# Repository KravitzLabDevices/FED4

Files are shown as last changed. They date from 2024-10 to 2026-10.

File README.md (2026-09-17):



<p align="center">
  FED4 Demo
</p>

**FED4** (Feeding Experimentation Device) is an open-source Arduino library for mouse operant training on board **v1.7**. Hardware details and chipsets: [`CHIPSETS.md`](CHIPSETS.md).

## Hardware features (v1.7)

- **MCU** — ESP32-S3  
- **Feeding** — stepper pellet dispenser with photogate well sensing and jam-clear paths  
- **Nose pokes** — three ESP32-S3 capacitive touch pads (left / center / right) with light-sleep wake  
- **Photogates** — four IR gates (left / center / right poke lanes + pellet / drop path)  
- **Display** — Kyocera TN0216 320×176 MIP reflective mono panel (SPI + VCOM)  
- **Storage** — microSD (SPI) for session CSV logging  
- **Clock** — DS3231 RTC  
- **Environment** — BME680 (temp / humidity / pressure / gas), VEML7700 ambient light  
- **Battery** — LiPo monitoring via MAX17048 fuel gauge  
- **Motion / proximity** — PIR (EKMB1107112); VL53L1X time-of-flight; LIS3DH accelerometer on board  
- **User I/O** — three front buttons; MCP23017 GPIO expander (rails, haptics, solenoids, display control)  
- **Feedback** — WS2812 front RGB strip, red status LED, haptic motor, MAX98357A I2S speaker amp  
- **Expansion** — TRRS / GPIO header (audio or digital); dual solenoid drivers; user expander pins; optional servo/INT  
- **Power** — switched peripheral rails (PSV2 / PSV3 via TPS22917) for sleep current control  
- **Optional wireless** — [Hublink](docs/wiki/Wireless-and-Hublink.md) BLE sync  

Library sketches stay small via an event-driven idle path: `waitUntil()` → act → `update()`.

In-lab test firmware flashes (version on the display, CSV `LibraryVer`) are tracked in [`docs/firmware/`](docs/firmware/).

## Examples

| Sketch | Role |
| --- | --- |
| [`BasicFED4`](examples/1_Programs/BasicFED4/) | Left poke → feed (starter program) |
| [`FreeFeeding`](examples/1_Programs/FreeFeeding/) | Replace pellet when taken |
| [`2_UnitTests/`](examples/2_UnitTests/) | Hardware bring-up / domain checks  |

More programs will return under [`examples/1_Programs/`](examples/1_Programs/) as domains are verified. Deeper API notes live in [`docs/wiki/`](docs/wiki/) and the [GitHub Wiki](https://github.com/KravitzLabDevices/FED4/wiki).

## In Development

Open work tracked in detail in [`examples/2_UnitTests/SRC_AUDIT.md`](examples/2_UnitTests/SRC_AUDIT.md):

- [ ] Rebuild menu + silence UX for v1.7 display  
- [ ] Retest / clean button holds (silence, menu, Mario / jingles)  
- [ ] Port remaining behavioral programs from archive → [`1_Programs`](examples/1_Programs/)  
- [ ] PIR / motion idle path (deferred to v1.8 counter IC)  
- [ ] Revisit ActivityMonitor when that sketch is unarchived  
- [ ] **Sense / camera** — TRRS TRIG + UART path in [`examples/3_Submodules/`](examples/3_Submodules/) (`FED4::senseSyncTime` / `senseTrigPulse`). Validate chamber lighting + fixed AE under strip white.  
- [ ] Characterize touch / SD card write duration to determine max touch rate

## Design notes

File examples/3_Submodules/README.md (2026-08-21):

# FED4 Submodule TRRS UART Specification

**Version:** v1.0 (TRIG + UART)

This directory holds **standalone firmware** for satellite boards that communicate with FED4 over a 4-wire TRRS-style link (power + TRIG + DATA). Submodule code is **not** part of the FED4 core library and does not use `FED4.h` or any `src/` APIs except the mirrored wire format documented here.

**FED4 master (library):** `src/FED4_Submodule.cpp` — `FED4::senseBegin()` / `senseSyncTime()` / `senseTrigPulse()`.

## Pin map

| Signal | FED4 | Sense (XIAO ESP32-S3) |
|---|---|---|
| 3V3 / GND | connector power | connector power |
| TRIG | `AUDIO_TRRS_2` = GPIO5 | GPIO1 (D0) |
| DATA | `AUDIO_TRRS_3` = GPIO6 | GPIO2 (D1) |
| spare | `AUDIO_TRRS_1` = GPIO4 | — |

- Idle **TRIG = HIGH** (Sense `INPUT_PULLUP`); FED4 drives **LOW** to wake / fire.
- **DATA:** half-duplex UART 115200 8N1, same GPIO for RX+TX; **external pull-up to 3.3 V** required.

## Shared slave helpers

| File | Role |
|---|---|
| [`SubmoduleProtocol.h`](SubmoduleProtocol.h) | Text frames, error codes |
| [`SubmoduleState.h/.cpp`](SubmoduleState.h) | `rtcValid`, last filename |
| [`SubmoduleRtc.h/.cpp`](SubmoduleRtc.h) | `settimeofday` / live clock |
| [`SubmoduleCommands.h/.cpp`](SubmoduleCommands.h) | `T` / `R` UART dispatch |
| [`SubmoduleUartEsp32.h/.cpp`](SubmoduleUartEsp32.h) | TRIG light-sleep wake, capture-blocks-sleep, UART poll |

Board folders (e.g. [`SeeedStudioSense/`](SeeedStudioSense/)) provide pin maps, camera backend, and a thin `.ino` plus `SubmodulePort.cpp` that `#include`s the shared `.cpp` files.

## Relationship to FED4

| | FED4 (master) | Submodules (slaves) |
|---|---|---|
| Role | TRIG + UART master | TRIG wake + capture |
| Code | `src/FED4_Submodule.cpp` + `FED4::sense*` | `examples/3_Submodules/` only |

## Protocol

### Init (synchronous)

1. FED4 TRIG LOW  
2. Sense wakes, UART up, sends `RDY\n`  
3. FED4 sends `T <yyyy> <mm> <dd> <HH> <MM> <SS>\n`  
4. Sense sets RTC, replies `OK\n` (or `ERR <code>\n`)  
5. FED4 TRIG HIGH → Sense light sleep  

Until `rtcValid`, Sense **does not capture** on TRIG (UART/`T` only).

### Capture (asynchronous — fire and forget)

1. FED4: TRIG LOW for **~10 ms**, then HIGH (`senseTrigPulse`). No UART wait for capture.  
2. Sense: on TRIG active + `rtcValid`, **one** capture to `YYYYMMDDHHMMSS.jpg` (blocking). **Do not light-sleep while capturing**, even if TRIG returns HIGH.  
3. After capture: if TRIG still LOW, accept UART (`T`, `R <name>`); if HIGH, light sleep.  
4. Next HIGH→LOW after a completed cycle starts a new capture.

### UART frames (init / post-capture session)

| Line | Direction | Meaning |
|---|---|---|
| `RDY` | Sense→FED4 | UART ready |
| `T yyyy mm dd HH MM SS` | FED4→Sense | SET_TIME |
| `R <filename>` | FED4→Sense | Rename last capture |
| `OK` | Sense→FED4 | Success |
| `ERR <code>` | Sense→FED4 | Failure |

Capture itself has **no** OK/ERR handshake on the wire.

## Submodule index

| Folder | Board | Status |
|---|---|---|
| [SeeedStudioSense](SeeedStudioSense/) | Seeed XIAO ESP32-S3 Sense | v1.0 — TRIG capture, SET_TIME, optional rename |

**FED4 master test:** [`FED4-Submodule-SeeedStudioSense`](../2_UnitTests/FED4-Submodule-SeeedStudioSense/) — `senseSyncTime` + `senseTrigPulse`.

## Changelog

### v1.0
- Replaced I2C @ 0x42 with TRRS TRIG + half-duplex UART.
- Async TRIG pulse capture; sync SET_TIME at init.

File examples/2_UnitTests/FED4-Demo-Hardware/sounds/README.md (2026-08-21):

# Boot startup sound (embedded PCM)

`startup_sound.h` holds 48 kHz mono 16-bit PCM played once at boot.

## Regenerate from a new clip

```bash
python3 sounds/gen_startup_sound.py /path/to/your-audio.mp3
```

Requires macOS `afconvert` for MP3 input, or pass a WAV already at 48 kHz mono 16-bit LE.

## Flash cost

~96 KB per second of audio (~2.5 s ≈ 232 KB for the current clip).

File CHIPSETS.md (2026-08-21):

# Specific chipsets used in FED4

| Subsystem | Chip / module | Notes |
| --- | --- | --- |
| Main platform | **ESP32 (ESP32‑S3 family)** | Main MCU (library `architectures=esp32`; code notes ESP32‑S3 specifics) |
| Power / battery | **MAX17048** | LiPo fuel gauge / battery monitor |
| Timekeeping | **DS3231** | Real-time clock (RTC) |
| I/O expansion | **MCP23X17** (MCP23017 family) | GPIO expander (photogates, haptics control, ToF XSHUT, etc.) |
| Environmental sensing | **BME680** | Temperature / humidity / pressure / gas |
| Environmental sensing | **VEML7700** | Ambient light |
| Motion / presence | **EKMB1107112** | PIR motion sensor (digital GPIO, replaces STHS34PF80) |
| Distance / proximity  | **VL53L1X** | Time-of-flight (ToF) distance / proximity |
| Inertial (optional) | **LIS3DH** | 3-axis accelerometer (hardware present; optional in sketches) |
| Audio | **MAX98357A** | I2S audio amplifier (speaker output) |
| LEDs | **WS2812-family** | RGB front strip; single red status LED |
| Display | **Kyocera TN0216ANVNANN-GN00** | 320×176 MIP reflective, 3-wire SPI, 1-bit monochrome; logical portrait 176×320 via rotation=3 |
| Optional wireless | **Hublink (BLE)** | Radio chipset not specified in this repo |

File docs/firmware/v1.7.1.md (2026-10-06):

# Firmware v1.7.1

Published library on board **v1.7.0**. Arduino-ESP32 core stays **3.2.1** (legacy `touch_pad`). Do not upgrade to 3.3.x / `touch_sens` NG.

---

## Production defaults

| Flag | Default | Notes |
| --- | --- | --- |
| `FED4_ENABLE_TOUCH_LOG` | **0** | Heartbeat `_T.CSV` is a diagnostic campaign. Schema, `logTouch()`, and row types stay in the code; rebuild the library with `=1` to re-enable. An `.ino` `#define` does not reach library sources. |
| `FED4_DIAG_POKE_TIMING` | **0** | Serial poke-path micros. Set to `1` and rebuild for a latency bench. |
| `FED4_DIAG_SKIP_SD_LOG` | `0` | Behavioral poke `logData` stays on. |

---

## Pad ID (do not confuse these)

- **Software pad index** (`FedPad` / CSV `Pad` / `LatchPad` / `ConfirmPad`): Left=**1**, Center=**2**, Right=**3**.
- **Hardware touch channel** (`[FED4_Pins.h](../../src/FED4_Pins.h)`): Left=**1**, Right=**2**, Center=**3**.
- **Pad ID is Latch + Confirm.** `fed4TouchPadIndexFromLatchOnly()` uses the edge-accumulated `status_mask` (`touch_pad_get_status()`). Confirm is `fed4TouchConfirmPadByAbsDelta()` (`ConfirmAgreed`). Do **not** put `touch_pad_get_current_meas_channel()` back into the latch or the arbiter.
- `IsrChan` **is diagnostic only.** It is that current-scan-channel register at ISR entry — whichever channel the FSM happens to be scanning, not the channel that went active. Do not use it (or `PeakWinner = argmax(PeakL,C,R)`) as ground truth. Left idle can sit above a light Right poke (e.g. Left idle ~16880 beats a light Right poke ~16000).

---

## What this firmware keeps

Relative to un-instrumented 1.7.0 production touch. Sources: `[FED4_Touch.cpp](../../src/FED4_Touch.cpp)`, `[FED4_TouchHelpers.h](../../src/FED4_TouchHelpers.h)`, `[FED4_Sleep.cpp](../../src/FED4_Sleep.cpp)`.

Evidence is from the 74.7 h field log `FED4_0000_20260905_00_T.CSV` (4436 rows, 2026-09-05 12:21 → 09-08 14:57).

| # | Change | Failure it fixes |
| --- | --- | --- |
| 1 | Shorter measurement | FSM stop (terminal) |
| 2 | Measurement-timeout recovery | FSM stop (terminal) |
| 3 | ISR status-mask edge | Wrong-pad identification |
| 4 | Confirm vote | Wrong-pad identification |
| 5 | Bounded pre-sleep release wait | Pre-sleep hang |
| 6 | Touch diagnostic CSV + version | Observability (off by default) |
| 7 | Gated 2 s rescue characterization | Idle poison after a long poke / dead FSM |

### 1. Shorter measurement — `TOUCH_MEASURE_CYCLES` 2000 → **200**

*Issue.* IDF recommends sizing this so one measurement takes ~1 ms. At 2000 cycles Left measured **9.7 ms** — a 10× overshoot. The raw value *is* the elapsed clock-cycle count, so a loaded pad scales it directly: the fatal poke read 2,343,997 counts, 13.8× baseline, which ran out of range and stopped the FSM. At a 22 ms scan cycle the 5 ms confirm window was also re-reading the same hardware value, so the "3 agreeing samples" vote was vacuous.

*How it addresses it.* Left's baseline drops to ~17,000 counts, so the same 13.8× load reads ~241,000 — comfortably in range. Headroom goes from ~10× to ~130×. Confirm and characterization samples become independent.

### 2. Measurement-timeout recovery — `touch_pad_timeout_set` / `touch_pad_timeout_resume`

*Issue.* v1.7.0 registered the ISR for `TOUCH_PAD_INTR_MASK_ACTIVE` only. `touch_sensor.h` warns that without `touch_pad_timeout_resume()`, the touch FSM stops after a timeout interrupt. That is exactly what happened — all six registers froze together and stayed frozen 24 h.

*How it addresses it.* Threshold is `TOUCH_MEASURE_CYCLES × TOUCH_TIMEOUT_MULTIPLIER` = 200 × 700 = 140,000 counts (~8× the largest pad's nominal). The ISR flags and counts the event; `fed4TouchServiceTimeout()` resumes from task context. An out-of-range reading costs one measurement instead of the device.

### 3. ISR latches the status-mask edge, not scan position

*Issue.* v1.7.0 stored `touch_pad_get_current_meas_channel()` — whichever channel the FSM is scanning *now*, not the one that raised the interrupt. Against ms-scale measurements the ISR always lands on the **next** channel in scan order (Left=ch1 → Right=ch2 → Center=ch3), producing a deterministic one-channel rotation.

*How it addresses it.* `sTouchActiveMask |= (status & ~sTouchPrevStatus)` uses `touch_pad_get_status()`, the register that actually says which channel is active. Taking the **edge** rather than the level matters after a pad strands: a level read would credit that pad on every wake forever. `chan_id` is retained as `IsrChan` — diagnostic only, never used for identification.

### 4. Confirm requires a real vote — `ConfirmAgreed`

*Issue.* `fed4TouchConfirmPadByAbsDelta()` returned its best single-sample candidate even with no agreeing run, and the arbiter gave confirm absolute priority. While the sensor was healthy, confirm overrode the skewed latch; as readings drifted from Idle, confirm abstained and the latch's deterministic error surfaced.

*How it addresses it.* Confirm returns 0 unless it genuinely voted (`TOUCH_ID_CONFIRM_AGREE` agreeing samples), so preferring it over a disagreeing latch is sound. This had to ship **with** change 3.

### 5. Bounded pre-sleep release wait — `ReleaseWait` / `Stuck`

*Issue.* `while (!fed4TouchPadsReleased(...))` had no timeout. If pads never read released, `waitUntil()` never returns — device alive, logging nothing.

*How it addresses it.* `FED4_TOUCH_RELEASE_WAIT_MS` (5 s) forces a break and proceeds to sleep with the timer wake still armed, recording `ReleaseWaitMs`. A hang becomes a logged event (`Stuck` if the hard cap, `ReleaseWait` if slow but released).

### 6. Gated 2 s rescue characterization — `fed4TouchAllPadsHwInactive`

*Issue.* After identify, `startSleep()` waits until software says the pads are released (`smooth − idle` vs rise thresh). The 2 s rescue re-runs `fed4TouchCharacterizePads()`so Idle is taken from the live, empty pads and “released” becomes true again. That is the case it is for.

The same path is lethal if it runs while a pad is **loaded**. Characterization samples Smooth for ~1.7 s (400 ms warm + 64 × 20 ms) and writes that mean into Idle.

*How it addresses it.* Keep the rescue for the empty-pad case. Do **not** run it when we just captured a poke (`wakePad != 0`) or when hardware still says active (`smooth − bench ≥ wakeAbs` on any pad). `fed4TouchAllPadsHwInactive()` is that hardware vote — the same check that would have blocked the 1.7.0 death (`SmoothL − BenchL ≈ 2.2M` vs `wakeAbs` 853) and every rechar (at the 500 ms poke, `SmoothR − BenchR` was ~9k vs 799).

If the poke is still down, the 5 s bounded wait (change 5) still applies: wait for release, or sleep anyway. There is no extra 1.7 s tax, and Idle stays at boot. A `Rechar` row after a 500 ms poke is a bug, not a success.

### 7. Touch diagnostic CSV + version trackability

`_T.CSV` schema and `logTouch()` stay in the library, compiled out when `FED4_ENABLE_TOUCH_LOG` is 0. When enabled: BootChar / Heartbeat / Poke / TouchMiss / Rechar / Stuck / ReleaseWait. Columns after `WakeCount`: `ScanPeriodUs`, `MeasUs{L,C,R}`, `TimeoutCount`, `StatusMask`, `IsrChan`, `IsrMask`, `IsrCount`, `Peak{L,C,R}`, `ConfirmAgreed`, `ReleaseWaitMs`.

Firmware identity `v1.7.1` is on the display footer, in the Serial boot line, and in CSV `LibraryVer`. Drift sketches report `AwakeDrift` / `SleepDrift`.

---

## Known expected Serial (Arduino-ESP32 3.2.1 / IDF 5.4)

Boot prints this immediately after `Initializing Battery Monitor`. It is **not** a missing MAX17048.

```text
Initializing Battery Monitor
E (...) i2c.master: I2C transaction unexpected nack detected
E (...) i2c.master: s_i2c_synchronous_transaction(945): I2C transaction failed
E (...) i2c.master: i2c_master_multi_buffer_transmit(1207): I2C transaction failed
```

Arduino-ESP32 3.2.1 uses IDF 5.4’s `i2c.master` driver, which logs **ERROR** on any unexpected NACK. `Adafruit_MAX17048::begin()` writes `0x5400` to COMMAND (POR). The MAX17048 datasheet specifies that this POR write is **NACKed**: the chip resets instead of ACKing the byte. That NACK is by spec. `[FED4_Begin.cpp](../../src/FED4_Begin.cpp)` then retries `begin()`; if the probe at `0x36` succeeded, the gauge is present. A real failure is `Battery monitor not on bus` or `Battery monitor initialization failed` after three retries.

---

## Known gaps (not this release)

All in `fed4TouchFilterConfig()` / characterization. Do not retune here.

| Location | Current | Why it matters |
| --- | --- | --- |
| `[FED4_Touch.cpp](../../src/FED4_Touch.cpp)` `noise_thr = 2` | Coefficient 2/8 → the benchmark's noise band is only `0.25 × threshold` | The displacement that stranded `BenchL` was 1,339 counts. `noise_thr = 3` would widen the band. |
| `smh_lvl = TOUCH_PAD_SMOOTH_OFF` | Smooth *is* raw | Zero rejection of a single bad sample. 22 % of pokes in the field log contaminated another pad's reading. |

NVS poke-delta calibration remains **WIP** (`begin()` does not auto-load it).

---

Full poke/touch background: `[docs/wiki/Poke-Functionality.md](../wiki/Poke-Functionality.md)`.

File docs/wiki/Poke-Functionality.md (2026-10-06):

# FED4 Poke (Nose-Poke) Functionality

Three nose-pokes (left / center / right) on ESP32-S3 capacitive touch pads (`[FED4_Pins.h](../../src/FED4_Pins.h)`). **Touch wakes** the device from light sleep; software resolves the pad, optionally logs, does a light UI update, and returns to the sketch.

This page covers the `waitUntil()` **poke path only** — not `fed4.feed()`.

**Sources:** `[FED4_Sleep.cpp](../../src/FED4_Sleep.cpp)`, `[FED4_Touch.cpp](../../src/FED4_Touch.cpp)`, `[FED4_SD.cpp](../../src/FED4_SD.cpp)`, `[FED4.cpp](../../src/FED4.cpp)` (`update` modes).

**GPIO map (face-on):** Left = GPIO1, Center = GPIO3, Right = GPIO2.

---

## Program path (BasicFED4-style)

```text
loop:
  FedEvent e = waitUntil()     // sleep → wake → detect → log → update → return
  if (e is Left) feed()        // OUT OF SCOPE here
```

Inside `waitUntil()` (default UI interval 60 s):

```text
noPix()
startSleep()
  ├─ wait pads released (pre-sleep; not on the wake critical path)
  ├─ optional displayIndicators + refresh
  ├─ clear touch active latch; enable touch / button / timer wake
  ├─ esp_light_sleep_start()          ★ CPU stopped until poke/button/timer
  └─ classify lastWakeSource          ★ t0 = wake (timing reset)
wakeUp()
  ├─ release VCOM LEDC, PSV2/PSV3 on, delay(1)
  ├─ reclaim SPI / I2C, delay(1)
  ├─ capturePoke() if touch           ★ pad ID + hold → pokeDuration
  └─ button checks if needed
checkLateRetrieval()                  // photogate; may log LatePelletTaken
classify FedEvent (pad / button)
redPix(1) only if Touch && pad set
logData("Left"|"Center"|"Right")      // touch + pad only; skip if FED4_DIAG_SKIP_SD_LOG
update(Poke | Full)                   // Touch+pad → Poke; timer/button → Full
return e                              ★ sketch resumes (next cycle)
```

Sketches act on `FedEvent` (`source` / `pad`); they do **not** need to call `logData` for the poke itself. CSV ENV/battery columns use the last `update(Full)` **→** `refreshSensors()` snapshot (timer wake), not a re-poll on every poke.

**Members:** `leftTouch` / `centerTouch` / `rightTouch`, `leftCount` / `centerCount` / `rightCount`, `pokeDuration` (ms of hold after identify). Boot sets idle + `wakeAbs` via live characterization (`fed4TouchCharacterizePads`).

**Pad identity after light sleep:** `esp_sleep_get_touchpad_wakeup_status()` is **deep-sleep-only** — unused here. Order in `capturePoke()`:

1. **Latch** — `on_active` `chan_id` / status_mask (who woke sleep)
2. **Confirm** — ~30 ms absolute `(smooth − idle)` vs per-pad `wakeAbs`; need 3 agreeing samples and a clear margin vs #2
3. **Arbiter** — latch==confirm → that pad; disagree → confirm; confirm-only or latch-only (quick tap) as fallbacks; neither → no poke

Pins (face-on): Left=GPIO1, Center=GPIO3, Right=GPIO2. Rise% first-cross is **not** used for sleep ID (false Left hits on high baseline).

---

## Touch numbers and `wakeAbs`

| Number | Source | Role |
| --- | --- | --- |
| **Smooth** | Driver live read (`touch_pad_filter_read_smooth`; SMOOTH_OFF → equals raw) | Current count; rises on poke |
| **Bench**  | Driver benchmark (`touch_pad_read_benchmark`, IIR8) | Hardware **baseline**; auto-tracks environmental drift |
| **Idle** | Software, at characterization | Software **baseline**; frozen until rechar / NVS apply |
| `wakeAbs`  | Software → `touch_pad_set_thresh` | Hardware **threshold**: counts above Bench (also the software floor vs Idle) |

Sleep wake: `smooth − bench >= wakeAbs`. Awake / confirm / pads-released: `smooth − idle` vs `wakeAbs`. After a sleep poke both apply — hardware wakes on Bench, `capturePoke()` confirms on Idle.

Constants live in `[FED4_TouchHelpers.h](../../src/FED4_TouchHelpers.h)`.

### In use today — live idle characterization

`begin()` → `initializeTouch()` → `fed4TouchCharacterizePads()`. Pads must be clear. Samples Smooth (warm 400 ms, then 64×20 ms), then:

```text
absDelta   = max(TOUCH_CHAR_SIGMA × std + TOUCH_CHAR_ABS_MARGIN, TOUCH_CHAR_ABS_MIN)
           = max(8 × std + 400, 800)
riseThresh = clamp(absDelta / idle, TOUCH_RISE_MIN, TOUCH_RISE_MAX)   // 0.005 … 0.12
wakeAbs    = idle × riseThresh
```

Absolute (not % of idle) so high-baseline pads (often Left ~220k) stay as sensitive as lower-baseline pads for similar poke capacitance. The 2 s `startSleep()` rescue re-runs this same formula only when software says pads are stuck **and** hardware agrees they are clear (`fed4TouchAllPadsHwInactive()`, and not right after a captured poke). A long hold must not rewrite Idle.

### WIP — NVS poke-delta calibration

Not used at boot. Wizard + NVS API exist; `begin()` does **not** auto-load. Future: `initializeTouch` loads `tchVer` when valid, else falls back to live char.

Guided **idle + poke-delta** stored in Preferences namespace `fed4` (follows the device, not the SD card). `fed4TouchCalDerivePad()`:

```text
touchDelta = touched − idle
wakeAbs    = clamp(TOUCH_CAL_DELTA_FRAC × touchDelta, TOUCH_CHAR_ABS_MIN, idle × TOUCH_RISE_MAX)
           = clamp(0.4 × touchDelta, 800, idle × 0.12)
riseThresh = wakeAbs / idle          // then re-clamped to 0.005 … 0.12
```

| Key | Meaning |
| --- | --- |
| `tchVer`  | Schema version (`FED4_TOUCH_CAL_VER` = 1) |
| `tchMap`  | Packed Left/Center/Right GPIO fingerprint (reject if pins remapped) |
| `tchBlob` | `Fed4TouchCal` POD: per-pad `idleMean`, `idleStd`, `touchDelta`, derived `wakeAbs` / `riseThresh` |

Wizard: `[examples/2_UnitTests/FED4-Touch-Calibrate/](../../examples/2_UnitTests/FED4-Touch-Calibrate/)` — BUTTON_1 confirms CLEAR (≥1.5 s quiet gate); auto onset/sustain/release on the prompted pad (×2 L→C→R; deltas within ~20%); `fed4TouchCalSave` / `Apply`. API in `[FED4_TouchHelpers.h](../../src/FED4_TouchHelpers.h)`; `FED4::touchCal*()` wrappers.

---

## Driver: production (legacy `touch_pad`) vs NG (`touch_sens`) WIP

**Production today** is the ESP-IDF **legacy** `touch_pad` path in `[FED4_Touch.cpp](../../src/FED4_Touch.cpp)` (`driver/touch_sensor.h`, Arduino-ESP32 3.2.1 / IDF 5.4): IIR8 benchmark, denoise BIT4/L4, SMOOTH_OFF, debounce 1. Light-sleep latch is the legacy `on_active` ISR (`chan_id` / `status_mask`).

**NG** `touch_sens` **is not compiled in**, and — on Arduino-ESP32 3.2.1 / IDF 5.4 for the S3 — cannot be: `driver/touch_sens.h` ships only for the P4 in that core, not the S3. Smooth / Bench / `wakeAbs` semantics above are the legacy filter/benchmark model.

### Build 1: field-failure root cause and fixes

A field unit degraded over ~2 days (wrong pad → missed pokes, worst on Left →
fully unresponsive). A 74.7 h `_T.CSV` capture traced the whole progression:

1. **The measurement was ~10x longer than IDF recommends** (`TOUCH_MEASURE_CYCLES`
  gave Left ~9.7 ms vs. the IDF-recommended ~1 ms), leaving almost no headroom
   before a loaded pad's measurement went out of range.
2. That out-of-range measurement **stopped the FSM permanently** — the legacy
  driver's measurement-timeout interrupt was never configured or handled, so
   `Smooth` and `Bench` froze on all three pads simultaneously.
3. **The rescue characterization accepted the frozen runaway value** (a 13.8x
  jump) into `Idle` with no plausibility check, making the damage irreversible
   even if the FSM had recovered.
4. Independently, the ISR's channel latch used `touch_pad_get_current_meas_channel()`
  — which reports whichever channel the FSM is scanning *right now*, not the
   channel that went active — producing a deterministic (not random) pad skew.

Fixed in `FED4_Touch.cpp`/`FED4_Sleep.cpp`/`FED4_TouchHelpers.h`: measurement
time reduced to target ~1 ms; `touch_pad_timeout_set()`/`touch_pad_timeout_resume()`
wired up (`fed4TouchServiceTimeout()`); the ISR latches
the `status_mask` edge instead of the current-scan-channel register;
the pre-sleep release wait is bounded at
`FED4_TOUCH_RELEASE_WAIT_MS` instead of spinning forever (logged as `Stuck`/
`ReleaseWait`); and the absolute-Δ confirm no longer returns an unvoted
single-sample winner (`ConfirmAgreed`). See the tunables block at the top of
`[FED4_TouchHelpers.h](../../src/FED4_TouchHelpers.h)` and the `_T.CSV`
columns (`ScanPeriodUs`, `MeasUs{L,C,R}`, `TimeoutCount`, `StatusMask`,
`IsrChan`, `IsrMask`, `IsrCount`, `Peak{L,C,R}`, `ConfirmAgreed`,
`ReleaseWaitMs`). `IsrChan` is diagnostic only — pad ID is Latch + Confirm.

---

## Latency model (wake → next cycle)

Times are **from CPU resume** after `esp_light_sleep_start` returns (**t0**), not from first contact. Contact → IRQ is extra (“Before t0”).

### Measured bench (Right poke, post–Poke-mode `update`)

Example Serial line:

```text
POKE_TIMING Right us: wake=15 wakeUp=140 preCap=8341 id=8355 capDone=147351
  class=147366 log=309338 update=414109 | gpioChan=3 mask=0xe
```

| Mark | µs (example) | Δ | Interpretation |
| --- | --- | --- | --- |
| `wake` | 15 | — | t0 |
| `wakeUp`  | 140 | ~0.1 ms | Enter `wakeUp()` |
| `preCap`  | 8341 | **~8.2 ms**  | Rail / SPI / I2C / `delay(1)`×2 |
| `id` | 8355 | **~0.01 ms** | Pad known (`gpioChan=3` → Right) |
| `capDone` | 147351 | **~139 ms**  | Hold until release (= `pokeDuration`) |
| `class` | 147366 | ≪1 ms | `FedEvent` + `redPix` |
| `log` | 309338 | **~162 ms**  | SD `logData("Right")` |
| `update`  | 414109 | **~105 ms**  | `FedUpdateMode::Poke` (counters/indicators + MIP `refresh`, no sensors) |

**Wake → return ≈ 414 ms** on this trial (hold + SD dominate; identify is negligible).

Earlier **Full** `update` after poke was often **~400–500 ms** alone (sensors + full clear/redraw). Poke mode cuts that to ~MIP refresh (~100 ms here).

### Stage summary

| Stage | What happens | Typical | Notes |
| --- | --- | --- | --- |
| **Before t0** | Pad rise, debounce, light-sleep exit | ~1–10+ ms | Not in `POKE_TIMING` |
| **Wake →** `wakeUp` | Cause classify | ~0.1–1 ms | |
| `wakeUp` **→** `preCap` | Rails, bus reclaim, `delay(1)`×2 | **~8 ms** measured | |
| **Identify (**`id`**)** | Latch + `(smooth − idle)` confirm | **≪1 ms** when latch hits | `gpioChan` confirms GPIO |
| **Hold (**`capDone − id`**)** | Until released (max 500 ms) | **≈ pokeDuration** | Usually largest term if held |
| `logData` | SD append | **~50–200 ms** typical | Touch rows only |
| `update(Poke)` | Counters + indicators + `refresh()` | **~100 ms** order | No `refreshSensors` |
| `update(Full)` | Sensors + full status redraw + Hublink | **~50–300+ ms** | Timer / button / post-`feed()` |

### Cumulative picture (touch poke)

```text
contact ──HW──► t0 ──~8ms──► id (~0) ──hold──► log ──update(Poke)──► return
                              │ gpioChan        │      │    ~100ms
                              └─ detection ─────┘      └─ SD often ~100–200ms
```

- **Detection** = `FED4_POKE_T_IDENTIFIED` (not `waitUntil` return).
- `pokeDuration` starts after identify; excludes sleep-exit and bring-up.
- Sketch code after `waitUntil()` runs only after hold + log + update.

### Non-touch wakes

Timer / button: no `capturePoke` / poke `logData`; `update(Full)`. Marks `preCap` / `id` / `capDone` stay 0.

---

## Hardware validation (`FED4_DIAG_POKE_TIMING`)

In `[FED4.h](../../src/FED4.h)` (production default is **0**; set to 1 and rebuild for a latency bench):

```cpp
#define FED4_DIAG_POKE_TIMING 0
```

On each resolved touch wake:

```text
POKE_TIMING Right us: wake=… wakeUp=… preCap=… id=… capDone=… class=… log=… update=… | gpioChan=3 mask=0xe
```

| Field | Meaning |
| --- | --- |
| `wake` … `update` | µs from t0 (see table above) |
| `gpioChan` | Raw `touch_pad_get_current_meas_channel()` at the last ISR entry — **diagnostic only** (see correction below); the authoritative channel map is `FED4_Pins.h`: **Left=1, Center=3, Right=2** |
| `mask` | Edge-accumulated active mask at the last consumer read (bit `N` ⇒ channel N newly active); may show multiple bits if more than one edge occurred between reads |

**Checks:** `id − preCap` ≈ identify; `capDone − id` ≈ hold; `log − class` ≈ SD; `update − log` ≈ Poke UI.

> **Correction (Build 1):** the worked example above (`gpioChan=3` labelled "Right", captured on a pre-fix build) and the legend that used to read *"2=Left, 1=Center, 3=Right"* were both wrong, and for the same reason: `gpioChan` was `touch_pad_get_current_meas_channel()`, which reports whichever channel the FSM happens to be scanning at ISR-entry time — not the channel that actually went active. Against millisecond-scale measurements the FSM has almost always already advanced to the *next* channel by the time the ISR runs, so Left(1) reported as 3(Center gone stale)/skewed, Right(2) reported as 3(Center), etc. That example is a captured instance of the bug, not a general truth about `gpioChan`. Pad identification no longer uses this register at all — `fed4TouchPadIndexFromLatchOnly()` uses the edge-accumulated `status_mask` (`touch_pad_get_status()`) instead; see `FED4_Touch.cpp`. `gpioChan`/`IsrChan` remain in the log as diagnostics only. Do not use them, or this example, to check "does `gpioChan` match the physical port" — use the CSV's `IsrMask`/`StatusMask` columns or the resolved `Pad`/`LatchPad`/`ConfirmPad` columns instead.

Disable (`0`) for normal runs — Serial/`flush` adds a little overhead.

API: `fed4PokeTimingReset` / `Mark` / `Print` in `[FED4_TouchHelpers.h](../../src/FED4_TouchHelpers.h)`.

---

## Touch diagnostic log (`FED4_ENABLE_TOUCH_LOG`)

Logs Smooth / Bench / Idle / `wakeAbs` side by side. Does **not** change calibration (`calibrateTouchSensors()`, 2 s rescue char, NVS). Library flag in `[FED4.h](../../src/FED4.h)` — rebuild required; an `.ino` `#define` does not reach library sources. Production default is **0** (heartbeat `_T.CSV` is a diagnostic campaign). Schema, `logTouch()`, and row types stay in the code.

```cpp
#define FED4_ENABLE_TOUCH_LOG 0
```

File pair (same suffix): `/FED4_<id>_<date>_<NN>.CSV` behavioral, `/FED4_<id>_<date>_<NN>_T.CSV` touch. Heartbeats ~1440 SD appends/day at 60 s; poke rows add a second append on the wake path.

| `RowType` | When |
| --- | --- |
| `BootChar` | After `logData("Startup")` |
| `Heartbeat` | Timer wake (idle sampled while quiet) |
| `Poke` | Touch + resolved pad (`PeakSmooth`, `PokeDuration`) |
| `TouchMiss` | Touch + no pad (behavioral CSV writes nothing) |
| `Rechar` | After `startSleep()` 2 s rescue (only if HW agrees pads are clear and this wake was not a poke) |
| `Stuck` | Pre-sleep release wait hit `FED4_TOUCH_RELEASE_WAIT_MS` |
| `ReleaseWait` | Release wait slow but pads released before the hard cap |

`Mode` is `LightSleep` or `Awake` (`touchLogMode` before `begin()`). Columns: identity, `Pad` / `LatchPad` / `ConfirmPad`, Smooth / Bench / Idle / Std, RiseThresh / WakeAbs, PeakSmooth / PokeDuration, RecharCount, ProxMm, ENV/battery (stale on `Poke` rows — last `update(Full)`), WakeCount. `LatchPad` is 0 on the awake arm. `ProxMm` is `-1` except Heartbeat / Rechar.

| Sketch | Arm | Task on display |
| --- | --- | --- |
| `[TouchDriftLog_Sleep](../../examples/3_Troubleshooting/TouchDriftLog_Sleep/)` | `waitUntil(60)`, `Mode=LightSleep` | **SleepDrift**  |
| `[TouchDriftLog_Awake](../../examples/3_Troubleshooting/TouchDriftLog_Awake/)` | Never sleeps; software `(smooth − idle)` pokes, `Mode=Awake` | **AwakeDrift**  |

Firmware identity (`v1.7.1`) is on the display footer and in CSV `LibraryVer`. Bump when `src/` changes — [firmware flash tracker](../firmware/README.md).

`[extras/analysis/fed4_touch_analysis.py](../../extras/analysis/fed4_touch_analysis.py)`: `python fed4_touch_analysis.py /path/to/sd_dumps -o out/`

| Observation | Conclusion |
| --- | --- |
| `Idle` flat, `Bench` rising, pokes dying | Hardware tracking absorbed occupant/drift |
| `Idle` jumps at `Rechar`, pokes die after | Recalibrated with a mouse nearby |
| Baselines stable, `PeakSmooth − Idle` shrinking | Sensitivity loss (coupling, debris) |
| Awake healthy, sleep dying | Light-sleep / benchmark / latch — not the pad |
| High `TouchMiss` | Identification failing, not detection |

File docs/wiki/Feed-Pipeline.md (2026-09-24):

# FED4 Feed Pipeline

How pellet delivery, awake retrieval timing, and **late retrieval** (after the 20 s window) work. Motor/jam hardware details: [Motor-and-Pellet-Dispensing.md](Motor-and-Pellet-Dispensing.md).

## Roles

| API | Owns |
|-----|---|
| **`feed()`** | Dispense (jam *clears* while motor still trying; **`DispenseError` only on hard give-up**), settle, well monitor **≤20 s** for **precise** `retrievalTime`, then `PelletTaken` **or** set **`pendingRetrieval`** if pellet still in well |
| **`waitUntil()` / sleep** | **PSV2/PSV3 off** in light sleep (battery). On wake, `checkLateRetrieval()` logs **`LatePelletTaken`** if the well is empty — coarse time, up to the UI interval (default 60 s) |

A pellet does **not** appear without the motor. Late handling is only for a pellet **already in the well** after the awake window. Photogate GPIO wake is **not** used (would require PSV2 on for the IR LED). Sketches do **not** need to call `checkLateRetrieval()` themselves.

**BasicFED4** (poke → feed):

```cpp
FedEvent e = fed4.waitUntil();
if (e.source == FedWakeSource::Touch && e.pad == FedPad::Left) {
  fed4.feed();
  fed4.update();
}
```

**FreeFeeding** (replace when taken — do not re-dispense while well occupied):

```cpp
if (fed4.checkForPellet()) {
  fed4.waitUntil(); // timer/touch wake; LatePelletTaken when pending + well empty
} else {
  fed4.feed();
  fed4.update();
}
```

## Why 20 s awake, then coarse late logging?

- **≤20 s in `feed()`:** stay awake and poll so `PelletTaken` retrieval times are accurate.
- **After 20 s still present:** light sleep with **PSV2 off** (~photogate mA saved). Next normal wake → power PSV2 → read well → **`LatePelletTaken`** if gone. Event name marks lost resolution vs in-window `PelletTaken`.

## Flowchart

```mermaid
flowchart TD
  init[initFeeding] --> dispense[dispense]
  dispense -->|jam clears motor still active| dispense
  dispense -->|hard give-up| jamEvt[log DispenseError]
  dispense -->|well or drop| dropEvt[log PelletDrop]
  dropEvt --> settle[settle up to 500ms]
  settle -->|never in well| notDet[terminal PelletNotDetected]
  settle -->|in well| well[monitor well up to 20s awake]
  well -->|well clears| taken[terminal PelletTaken precise time]
  well -->|poke while present| withPellet[log WithPellet keep retrievalTime]
  withPellet --> well
  well -->|still present at 20s| pending[pendingRetrieval]
  pending --> sleep[waitUntil light sleep PSV2 off]
  sleep -->|timer touch or button wake| check[checkLateRetrieval]
  check -->|well empty| lateTaken[LatePelletTaken coarse]
  check -->|still full| sleep
```

## CSV events

| Event | When |
|---|---|
| `PelletDrop` | Dispense succeeded (well and/or drop); count incremented |
| `LeftWithPellet` / `CenterWithPellet` / `RightWithPellet` | Poke while pellet in well (does not clear retrieval time) |
| `PelletTaken` | Well cleared **during** the awake ≤20 s window (precise `RetrievalTime`) |
| `LatePelletTaken` | Well cleared **after** that window (checked on `waitUntil` wake; coarse time) |
| `PelletNotDetected` | `PelletDrop` but well empty after settle — not a late-retrieval case |
| `DispenseError` | Hard jam give-up only (`jammed()`) — not during jam-clear moves |

ENV/battery on every row: last `update()` → `refreshSensors()` snapshot.

## Gaps identified → remedies

| Gap | Remedy |
|-----|---|
| Photogate wake needs PSV2 (IR LED ~2.5–3 mA) | Drop photogate wake; **PSV2 off** in light sleep; accept coarse `LatePelletTaken` |
| Late take only visible on UI interval | Intentional trade for weeks of battery; event name flags resolution |
| Sketch had to call `checkLateRetrieval()` | Still library-owned inside `waitUntil` / `feed` entry |
| “Wait for pellet to appear” after settle miss | Removed — late = late **take** of pellet still in well |
| `DispenseError` during jam clears | Error only from `jammed()` |

## Notes

- Before `PSV2_OFF()`, photogate and I2S GPIOs are driven LOW to limit back-power into 3.3V2.
- `feed()` also calls `checkLateRetrieval()` at entry before a new dispense.

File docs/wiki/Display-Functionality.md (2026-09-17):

# FED4 Display (Screen) Functionality

The FED4 uses a **Sharp Memory Display** (SPI, **DISPLAY_CS** = 17), **144×168** pixels, 1-bit (black/white). The FED4 class extends **Adafruit_GFX**, so you can use standard GFX calls (`drawPixel`, `fillRect`, `print`, `drawLine`, etc.) plus FED4-specific helpers.

**Initialization and refresh**

- **`initializeDisplay()`** — init display, allocate buffer, clear (called from `begin()`).
- **`updateDisplay()`** — full status redraw (task, mouse ID, env, battery, SD, counters, indicators, date/time). Used by `update(Full)`.
- **`updateDisplayPoke()`** — counters + indicators only (no buffer clear). Used by `update(Poke)` after touch in `waitUntil()`.
- **`refresh()`** — push the backing buffer to the display. Call after drawing.
- **`clearDisplay()`** — clear buffer (white) and refresh.

**`update()` modes** (`FedUpdateMode`): **Full** (default) = sensors + full UI + Hublink; **Poke** = skip sensors, patch counters/indicators, serial only. Timer wakes and post-`feed()` keep Full for research telemetry.

**Status helpers (used by `updateDisplay`)**

- **`displayHeader()`** — top bar: `MM/DD` · centered `H:MMam/pm` · battery.
- **`displayFooter()`** — bottom bar: `XXC RH%` · `v`+`libraryVer`. See [firmware flash tracker](../firmware/README.md).
- **`displayTask()`**, **`displayFilename()`** (`File: ` + SD log short name), **`displayMouseId()`**, **`displaySDCardStatus()`**, **`displayCounters()`**, **`displayIndicators()`** — status body.
- **`drawFooterBar()`** — RTC menu footer only (date · time · version).
- **`displayActivityMonitor()`** / **`displayActivityCounters()`** — when program is ActivityMonitor.
- **`displayInitStatus(msg)`** — show init message during `begin()`.
- **`displayLowBatteryWarning()`** — low-battery full-screen message.

**Constants:** `DISPLAY_WIDTH` = 144, `DISPLAY_HEIGHT` = 168; **`DISPLAY_BLACK`**, **`DISPLAY_WHITE`**, **`DISPLAY_INVERSE`**, **`DISPLAY_NORMAL`**.

See [FED4_Display.cpp](https://github.com/KravitzLabDevices/FED4/blob/main/src/FED4_Display.cpp), [FED4.h](https://github.com/KravitzLabDevices/FED4/blob/main/src/FED4.h). [Adafruit Sharp Memory Display](https://learn.adafruit.com/adafruit-sharp-memory-display-breakout), [Adafruit_GFX](https://github.com/adafruit/Adafruit-GFX-Library).

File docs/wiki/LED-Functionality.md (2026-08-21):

# FED4 LED Functionality

The FED4 has **two LED systems**: a **front strip** of 8 NeoPixels around the nose-pokes, and a **single digital status LED** on `STATUS_LED`.

**Front strip (poke lights)**

- **`leftLight("red")`**, **`centerLight("green")`**, **`rightLight("blue")`** — light left/center/right poke; optional brightness: `leftLight("red", 100)`.
- **`setStripPixel(i, "green")`** — individual strip LED.
- **`colorWipe("white", 10)`**, **`stripRainbow(50, 1)`** — animations; **`lightsOff()`** — clear strip.

**Status LED**

- **`redPix(brightness)`** — on when brightness > 0 (digital; PWM path is reserved for MIP VCOM LEDC).
- **`noPix()`** — off.

**Strip colors:** `"red"`, `"green"`, `"blue"`, `"yellow"`, `"purple"`, `"cyan"`, `"orange"`, `"white"`.

See [FED4_LEDs.cpp](https://github.com/KravitzLabDevices/FED4/blob/main/src/FED4_LEDs.cpp).

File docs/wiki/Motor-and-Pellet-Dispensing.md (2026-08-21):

# FED4 Motor and Pellet Dispensing

The FED4 drives a **stepper motor** to rotate a hopper and dispense pellets. For the full **feed → settle → well monitor → late pellet** event pipeline (flowchart, CSV events, gaps/remedies), see **[Feed-Pipeline.md](Feed-Pipeline.md)**.

**Motor**

- **Stepper:** 4-phase, 512 steps/rev. Pins **MOTOR_PIN_1–4** (46, 37, 21, 38); **MOTOR_SPEED** = 24. **Battery required** for motor operation.
- **`initializeMotor()`** — configure pins, set speed (called from `begin()`).
- **`releaseMotor()`** — coil pins LOW to save power between moves.
- **`motorTurns`** — counts small steps during dispense; ~**25** ≈ one pellet position, ~**1000** ≈ one hopper rotation. Logged (as `motorTurns/25`) on terminal feed events.

**Jam handling**

- **`minorJamClear()`** — 200 steps, 1 s pause (at ~100 motorTurns). **`vibrateJamClear()`** — short back‑and‑forth wobble (at ~200 motorTurns).
- **`jammed()`** — after **2000** motorTurns without dispense: **only then** **`logData("DispenseError")`** (hard give-up). Jam *clears* at 100/200 turns do **not** log an error while the motor is still trying.

**Sensors:** **`checkForPellet()`** — well photogate **PHOTOGATE_1**. **`didPelletDrop()`** — optional drop sensor **PHOTOGATE_4**.

See [FED4_Motor.cpp](https://github.com/KravitzLabDevices/FED4/blob/main/src/FED4_Motor.cpp), [FED4_Feed.cpp](https://github.com/KravitzLabDevices/FED4/blob/main/src/FED4_Feed.cpp), [FED4_Pins.h](https://github.com/KravitzLabDevices/FED4/blob/main/src/FED4_Pins.h).

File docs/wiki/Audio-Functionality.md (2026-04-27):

# FED4 Audio Functionality

The FED4 uses an **I2S-driven speaker** (MAX98357A). Audio is initialized in `begin()`.

**Tones and beeps**

- **`playTone(frequency, duration_ms, amplitude)`** — single tone (e.g. `playTone(500, 200, 0.25)`).
- **`lowBeep()`** — 500 Hz, 200 ms. **`highBeep()`** — 1000 Hz. **`higherBeep()`** — 2000 Hz.
- **`click()`** — short click (quick feedback).
- **`bopBeep()`** — two-tone beep (1000 Hz → 1600 Hz).

**Jingles**

- **`playStartup()`** — startup melody. **`resetJingle()`** — power-cycle jingle. **`menuJingle()`** — menu arpeggio.

**"Super Mario"-style sound effects (tone synthesis)**

- **`marioCoin()`** — coin pickup sound (approx).
- **`marioJump()`** — jump sound (approx).
- **`marioPipe()`** — pipe/travel “bloop” (approx).
- **`marioFireball()`** — fireball shot sound (approx).
- **`marioMushroom()`** — power-up sound (approx).

**Other**

- **`soundSweep(startFreq, endFreq, duration_ms)`** — frequency sweep. **`noise(duration_ms, amplitude)`** — white noise.
- **`silence()`** / **`unsilence()`** — mute audio (persists across reboots). **`enableAmp(bool)`** — amp on/off. **`resetSpeaker()`** — reinit I2S.

See [FED4_Audio.cpp](https://github.com/KravitzLabDevices/FED4/blob/main/src/FED4_Audio.cpp).

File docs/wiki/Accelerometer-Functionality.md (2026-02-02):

# FED4 Accelerometer Functionality

The FED4 has a **LIS3DH** accelerometer on the secondary I2C bus (address **0x19**). **It is currently not used** by any built-in FED4 programs; the API is available for custom sketches.

**API**

- **`initializeAccel()`** — init sensor (called from `begin()`). Default: ±2g, 50 Hz, high-resolution (12-bit).
- **`readAccel(x, y, z)`** — read acceleration in **m/s²**, remapped to device axes (x = left/right, y = forward/back, z = up/down).
- **`getAccelEvent(&event)`** — raw chip axes via `sensors_event_t`.
- **`setAccelRange(...)`**, **`setAccelDataRate(...)`**, **`setAccelPerformanceMode(...)`** — configure range (±2/4/8/16 g), rate (1–400 Hz), and mode (low-power / normal / high-res).
- **`accelDataReady()`** — `true` when new data is available.

See [FED4_Accel.cpp](https://github.com/KravitzLabDevices/FED4/blob/main/src/FED4_Accel.cpp). Example: [FED4-Accel-Test](https://github.com/KravitzLabDevices/FED4/tree/main/examples/3_Troubleshooting/HardwareExamples/FED4-Accel-Test).

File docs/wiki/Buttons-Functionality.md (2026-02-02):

# FED4 Buttons Functionality

The FED4 has **three user buttons** (GPIO **BUTTON_1** = 40, **BUTTON_2** = 39, **BUTTON_3** = 14), arranged bottom / middle / top. They use internal pull-down and can **wake the device** from light sleep. There is **no general-purpose “button pressed” API** for sketches; the library assigns fixed behaviors.

**Default behavior (on wake)**

- **`checkButton1()`** — **Button 1 (bottom):** Hold ~1 s → test pellet dispense (`feed()`), `bopBeep()`.
- **`checkButton2()`** — **Button 2 (middle):** Hold ~1 s → **device reset** (red wipe, `resetJingle()`, `esp_restart()`).
- **`checkButton3()`** — **Button 3 (top):** Hold **500 ms** → **audio toggle** (`silence` / `unsilence`), plus `click()`. Hold **1500 ms** → **menu** (`menu()`), `hapticDoubleBuzz()`.

These are run from **`wakeUp()`** after a **button** wake (not touch). Poll with **`digitalRead(BUTTON_1)`** etc. (HIGH = pressed) if you need raw state elsewhere (e.g. menu, dispense loop).

See [FED4_Buttons.cpp](https://github.com/KravitzLabDevices/FED4/blob/main/src/FED4_Buttons.cpp), [FED4_Pins.h](https://github.com/KravitzLabDevices/FED4/blob/main/src/FED4_Pins.h).

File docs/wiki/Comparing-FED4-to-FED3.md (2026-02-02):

# FED4 vs FED3 (Quick Comparison)

This page summarizes high‑level differences using the **FED4 README** and the **FED3 specifications/wiki**. Where FED4 specs are not published, the table notes “not listed.”

## At a glance

| Category | FED4 | FED3 |
|---|---|---|
| **Core purpose** | Feeding experimentation device; integrated environmental monitoring and data logging | Feeding experimentation device |
| **Nose‑pokes** | Three | Three (per FED3 wiki) |
| **Pellet dispenser** | Updated design; **dispensing is greatly improved vs FED3** | Legacy FED3 dispenser |
| **Wireless / cloud** | Optional **Hublink** (BLE → gateway → hublink.cloud), auto‑configured via `meta.json` | Not listed in FED3 specs/wiki |
| **Screen** | Sharp Memory Display, 144×168 (from FED4 code) | Sharp Memory Display (FED3 wiki) |
| **Battery** | Not listed in FED4 README | 3.7 V 4400 mAh (FED3 wiki) |
| **Weight** | Not listed in FED4 README | 295 g (FED3 wiki) |
| **Dimensions** | Not listed in FED4 README | 135×85×86 mm (FED3 wiki) |
| **Processor** | Not listed in FED4 README | Feather M0 Adalogger (FED3 wiki) |

## FED4 highlights (from FED4 README)

| Area | FED4 highlights |
|---|---|
| **Sensors** | BME680 (temp/humidity/pressure/gas), VEML7700 (ambient light), VL53L1X (ToF), STHS34PF80 (motion), DS3231 RTC, plus LIS3DH accel + MLX90393 magnetometer (hardware present; currently unused in default programs) |
| **Outputs** | Multicolor nose‑poke LEDs, audio, haptic, SD logging |
| **Wireless** | Optional Hublink; enable with `fed.useHublink = true` and it syncs automatically in `run()` |

## FED3 specs (from FED3 wiki)

| Spec | FED3 |
|---|---|
| **Weight** | 295 g |
| **Dimensions** | 135×85×86 mm |
| **Processor** | Feather M0 Adalogger |
| **Screen** | Sharp Memory Display |
| **Battery** | 3.7 V 4400 mAh (~7 days continuous) |
| **Pellets** | 20 mg precision pellets (TestDiet, Bio‑Serv, etc.) |

## Sources

- FED4 README: https://github.com/KravitzLabDevices/FED4  
- FED3 specifications (wiki): https://github.com/KravitzLabDevices/FED3/wiki/FED3-Specifications  
- FED3 library: https://github.com/KravitzLabDevices/FED3_library

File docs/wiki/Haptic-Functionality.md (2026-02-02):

# FED4 Haptic Functionality

The FED4 drives a **haptic motor** via the MCP expander (pin **EXP_HAPTIC**). Used for vibration feedback on pokes, buttons, and events.

**Functions**

- **`hapticBuzz(duration)`** — single buzz (default 100 ms).
- **`hapticDoubleBuzz(duration)`** — two buzzes (default 25 ms each).
- **`hapticTripleBuzz(duration)`** — three buzzes (default 5 ms base; on/off = duration×10).
- **`hapticRumble(duration_ms)`** — low-frequency PWM rumble (default 300 ms, 50 Hz).

Durations are in milliseconds unless noted. See [FED4_Haptic.cpp](https://github.com/KravitzLabDevices/FED4/blob/main/src/FED4_Haptic.cpp).

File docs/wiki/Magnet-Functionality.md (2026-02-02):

# FED4 Magnet (Magnetometer) Functionality

The FED4 has an **MLX90393** magnetometer on the secondary I2C bus (address **0x0C**). **It is currently not used** by any built-in FED4 programs; the API is available for custom sketches.

**API**

- **`initializeMagnet()`** — init sensor (called from `begin()`). Uses **`configureMagnet()`** with default gain (5×).
- **`readMagnetData(x, y, z)`** — read magnetic field (µT) into `float` refs. Returns `true` on success.
- **`getMagnetEvent(&event)`** — raw data via `sensors_event_t`.
- **`setMagnetGain(...)`** / **`getMagnetGain()`** — configure or read gain (e.g. `MLX90393_GAIN_5X`).
- **`configureMagnet(gain)`** — set gain, resolution, oversampling, and filter (default 5× gain).

See [FED4_Magnet.cpp](https://github.com/KravitzLabDevices/FED4/blob/main/src/FED4_Magnet.cpp). Hardware: [Adafruit MLX90393](https://www.adafruit.com/product/4022), [Adafruit library](https://github.com/adafruit/Adafruit_MLX90393_Library).

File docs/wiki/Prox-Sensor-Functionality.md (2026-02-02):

# FED4 Prox (Proximity) Sensor Functionality

The FED4 uses a **VL53L1X time-of-flight (ToF)** distance sensor on the primary I2C bus (XSHUT on MCP pin 1). Measures approach distance to the nose port.

**API**

- **`initializeToF()`** — init ToF sensor (called from `begin()`). Returns `true` on success.
- **`prox()`** — take a single distance reading. Returns **distance in mm** (0–150), or **`-1`** on error/timeout.

**Details**

- Raw reading is offset by a **20 mm calibration** (configurable in code). Values &lt; 0 are clamped to 0; &gt; 150 mm are capped at 150.
- Used for approach detection (e.g. Pavlovian_Prox) and to exercise the primary I2C bus before secondary use (e.g. in `pollSensors()`).

See [FED4_Prox.cpp](https://github.com/KravitzLabDevices/FED4/blob/main/src/FED4_Prox.cpp). Hardware: [SparkFun VL53L1X](https://www.sparkfun.com/products/14722), [SparkFun Arduino library](https://github.com/sparkfun/SparkFun_VL53L1X_Arduino_Library).

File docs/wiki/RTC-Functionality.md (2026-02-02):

# FED4 RTC (Real-Time Clock) Functionality

The FED4 uses a **DS3231 RTC** on the secondary I2C bus to keep accurate time across power cycles. Time is used for **logs, display, and scheduling**.

**Initialization and auto-update**

- **`initializeRTC()`** — starts the DS3231 and loads time into the internal clock. On **new compilation**, the RTC is updated to the build time.
- **Compilation detection** — a stored compile timestamp in Preferences triggers **`updateRTC()`** only when firmware changes.

**Key API**

- **`now()`** — returns `DateTime` from the RTC.
- **`updateTime()`** — updates `currentHour`, `currentMinute`, `currentSecond`, `unixtime`.
- **`adjustRTC(timestamp)`** — sets RTC from a Unix timestamp (used by Hublink time sync).

**Logging**

- **`ElapsedSeconds`** in the SD log is **millis-based**, rounded to **0.001 s** (1 ms resolution).

**Manual set**

- **`menuRTC()`** — interactive RTC setting in the FED4 menu.

See [FED4_RTC.cpp](https://github.com/KravitzLabDevices/FED4/blob/main/src/FED4_RTC.cpp), [RTClib](https://github.com/adafruit/RTClib).

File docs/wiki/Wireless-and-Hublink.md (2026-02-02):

# FED4 Wireless Capabilities and Hublink

The FED4 supports **wireless connectivity** via **Hublink**, which uses **BLE** to connect nodes (FED4) to a gateway, and the gateway to **[hublink.cloud](https://hublink.cloud)** for time sync, file uploads, and alerts. FED4 is **automatically configured for hublink.cloud** through the **`meta.json`** file on the SD card—no Hublink-specific code is required beyond enabling it.

**Automatic configuration (meta.json)**

- The **`meta.json`** schema is **compatible with hublink.cloud**. A **`hublink`** section configures BLE advertising and upload behavior:
  - **`advertise`** — BLE advertising name (e.g. `"FED4"`).
  - **`advertise_every`** — seconds between advertising periods (e.g. 300).
  - **`advertise_for`** — duration of each advertising period in seconds (e.g. 30).
  - **`upload_path`**, **`append_path`** — where files go in cloud storage (e.g. `/FED`, `subject:id`).
  - **`disable`** — set `true` to turn Hublink off.
- **`subject`**, **`device`**, etc. in **`meta.json`** are used for metadata and paths. The same file drives both FED4 metadata and Hublink; **one config, automatically applied** when Hublink is enabled.

**Enabling Hublink**

- Set **`fed.useHublink = true`** before **`fed.begin(...)`**. **`begin()`** then calls **`initializeHublink()`** (reads **`meta.json`**, starts Hublink). **`run()`** calls **`syncHublink()`** before sleep—**sync is automatic** each wake cycle.
- **`initializeHublink()`** — init Hublink (uses **SD_CS** pin); registers **`onHublinkTimestampReceived`** for RTC updates.
- **`syncHublink()`** — sets battery level, low-battery alerts, and runs **`hublink.sync()`** (advertise/connect, upload files, receive time).

**What runs automatically**

- **RTC time sync** — timestamps from Hublink update the RTC via **`adjustRTC()`**.
- **Low-battery alerts** — battery under 20% triggers **`hublink.setAlert("Low Battery!")`** before sync.
- **File uploads** — log files (and **`meta.json`**) are uploaded according to **`upload_path`** / **`append_path`** when the gateway is in range.

**Optional exclusion**

- **`#define FED4_EXCLUDE_HUBLINK`** before **`#include <FED4.h>`** removes Hublink from the build to save code size.

**Requirements:** Hublink library, SD card with **`meta.json`**, gateway in range for BLE, and internet for the gateway → hublink.cloud.

See [FED4_Hublink.cpp](https://github.com/KravitzLabDevices/FED4/blob/main/src/FED4_Hublink.cpp), [Hublink examples](https://github.com/KravitzLabDevices/FED4/tree/main/examples/4_Hublink), [meta.json example](https://github.com/KravitzLabDevices/FED4/blob/main/extras/meta.json_examples/meta.json). Full config and cloud usage: **[hublink.cloud/docs](https://hublink.cloud/docs)**.

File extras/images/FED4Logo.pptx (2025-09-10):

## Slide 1

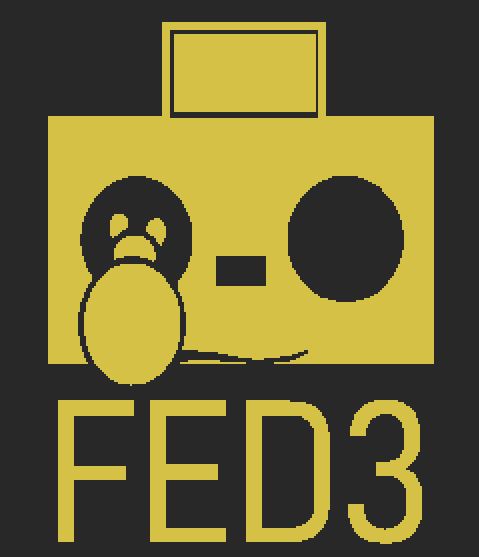
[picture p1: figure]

FED3

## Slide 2

FED4

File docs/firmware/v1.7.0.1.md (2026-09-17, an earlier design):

# Firmware v1.7.0.1

## What changed in this firmware (library)

Relative to un-instrumented 1.7.0 production touch. Sources: `[FED4_Touch.cpp](../../src/FED4_Touch.cpp)`, `[FED4_TouchHelpers.h](../../src/FED4_TouchHelpers.h)`, `[FED4_Sleep.cpp](../../src/FED4_Sleep.cpp)`.

Every change below traces to a specific failure in the 74.7 h field log `FED4_0000_20260905_00_T.CSV` (4436 rows, 2026-09-05 12:21 → 09-08 14:57), which captured the whole degradation at minute resolution. Evidence is quoted per item.

| # | Change | Failure it fixes |
| --- | --- | --- |
| 1 | Shorter measurement | FSM stop (terminal) |
| 2 | Measurement-timeout recovery | FSM stop (terminal) |
| 3 | ISR status-mask edge | Wrong-pad identification |
| 4 | Confirm vote | Wrong-pad identification |
| 5 | Characterization bounds | Poisoned calibration (unrecoverable) |
| 6 | Stale-benchmark watchdog | 43 h benchmark freeze |
| 7 | Bounded pre-sleep release wait | Pre-sleep hang |
| 8 | Touch diagnostic CSV | Observability |
| 9 | Version trackability | Observability |

### What the field log actually showed

| When | Event |
| --- | --- |
| 09-05 12:21 | Boot. `BenchL` seeded well — 170,231 vs `IdleL` 170,264, 33 counts apart. Healthy. |
| 09-06 11:55–16:46 | 55 °C excursion (25.6 → 80.5 °C). `SmoothL` drifts **4,176 counts**; `BenchL` tracks it with a **44-count residual**. Temperature is *not* a factor. |
| 09-06 17:58 | Poke burst. A poke on **Right** drives **Left** to 249,583 (1.47× baseline). `BenchL` is dragged **1,339 counts** below the true sleeping baseline.  |
| 09-06 18:35 | Stranded > `wakeAbs` (853) latches Left active, which freezes its benchmark. `BenchL` frozen at 164,679 for **43 h** — 2,608 identical heartbeats. |
| 09-06 18:35 → | Confirm abstention doubles **21 % → 44 %**. Every abstention hands pad ID to the skewed latch, so wrong-pad attribution doubles. |
| 09-07 14:34 | Poke on Left reads **2,343,997 counts = 134 ms**. Measurement timeout, never handled → **FSM stops**. All six Smooth/Bench registers freeze. |
| 09-07 14:35 | Rescue characterization samples the dead sensor 64× — `Std = 0.0 / 0.0 / 0.0`. Writes `IdleL = 2,343,997`, `WakeAbsL = 11,719`. |
| 09-07 14:35 → end | 1,434 rows, zero pokes, `RecharCount` stuck at 2, battery 84 %, clean 60 s heartbeats. **Silent death.** |

---

### Group A — the terminal death (FSM stopped)

**1. Shorter measurement** — `TOUCH_MEASURE_CYCLES` 2000 → **200**

*Why.* IDF recommends sizing this so one measurement takes ~1 ms. At 2000 cycles Left measured **9.7 ms** (170,000 counts ÷ 17.5 MHz RTC_FAST) — a 10× overshoot. The raw value *is* the elapsed clock-cycle count, so a loaded pad scales it directly: the fatal poke read 2,343,997 counts, 13.8× baseline, which ran out of range and stopped the FSM.

*How it resolves it.* Left's baseline drops to ~17,000 counts, so the same 13.8× load reads ~241,000 — comfortably in range. Headroom goes from ~10× to ~130×. It also fixes a quieter problem: at a 22 ms scan cycle the 5 ms confirm window and 20 ms characterization interval were **re-reading the same hardware value**, which is why `StdL` was 37.5 on a 170,000 baseline (0.02 %) and the "3 agreeing samples" vote was vacuous.

**2. Measurement-timeout recovery** — `touch_pad_timeout_set` / `touch_pad_timeout_resume`

*Why.* v1.7.0 registered the ISR for `TOUCH_PAD_INTR_MASK_ACTIVE` only. `touch_sensor.h` warns that without `touch_pad_timeout_resume()`, *"the touch FSM will stop the measurement after timeout interrupt."* That is exactly what happened — all six registers froze together and stayed frozen 24 h.

*How it resolves it.* Threshold is `TOUCH_MEASURE_CYCLES × TOUCH_TIMEOUT_MULTIPLIER` = 200 × 700 = 140,000 counts (~8× the largest pad's nominal), expressed as a multiplier so it auto-scales if cycles are retuned. The ISR flags and counts the event; `fed4TouchServiceTimeout()` resumes from task context and prints `Touch: measurement timeout — FSM resumed`. An out-of-range reading costs one measurement instead of the device.

### Group B — wrong-pad identification

**3. ISR latches the status-mask edge, not scan position**

*Why.* v1.7.0 stored `touch_pad_get_current_meas_channel()` — whichever channel the FSM is scanning *now*, not the one that raised the interrupt. Against ms-scale measurements the ISR always lands on the **next** channel in scan order (Left=ch1 → Right=ch2 → Center=ch3), producing a deterministic one-channel rotation: touch Right → reports Center, touch Left → reports Right, touch Center → reports Left. The log's modal `LatchPad` matches all three predictions.

*How it resolves it.* `sTouchActiveMask |= (status & ~sTouchPrevStatus)` uses `touch_pad_get_status()`, the register that actually says which channel is active — the same source NG's `event->chan_id` derived from. Taking the **edge** rather than the level matters specifically here: after Left's benchmark stranded, Left sat permanently in `status`, and a level read would have credited Left on every wake forever. `TOUCH_PAD_INTR_MASK_INACTIVE` is handled too so `prevStatus` clears on release. `chan_id` is retained but logged as `IsrChan` — diagnostic only, never used for identification. `fed4TouchPadIndexFromLatchOnly()` returns a pad only when exactly one channel edged; zero edges returns 0 and falls through rather than guessing; multiple edges fall back to strongest `smooth − benchmark`, a physical measurement rather than a scan-position artifact.

**4. Confirm requires a real vote** — `ConfirmAgreed`

*Why.* `fed4TouchConfirmPadByAbsDelta()` returned its best single-sample candidate even with no agreeing run, and the arbiter gave confirm absolute priority. This is why the wrong-pad symptom appeared at ~30 h rather than at boot: the skew was at full strength from the first boot, but confirm (comparing `smooth − Idle`) was accurate while the sensor was healthy and overrode it. As the benchmark stranded and readings drifted from `Idle`, confirm abstained twice as often and the latch's deterministic error surfaced. In the log, `Pad == LatchPad` count *exactly equals* the confirm-abstention count in both eras (5/24 before, 15/34 after) — direct proof the latch only decided when confirm gave up.

*How it resolves it.* Confirm returns 0 unless it genuinely voted, so preferring it over a disagreeing latch is sound. This had to ship **with** change 3 — fixing the latch alone would have been worse, since more decisions fall through to it.

### Group C — permanent, unrecoverable states

**5. Characterization plausibility bounds + hardware gate** — `CalReject`

*Why.* This is what made the failure irreversible. With the FSM dead, `fed4TouchPadsReleased()` compared frozen `SmoothL` (2,343,997) against `IdleL` (170,729) → 1273 % rise → "stuck" → the 2 s rescue fired `fed4TouchCharacterizePads()`, which sampled a dead sensor 64 times (`Std = 0.0` on all three channels — a standard deviation of exactly zero across three independent channels is only possible if the hardware stopped) and wrote the garbage into `Idle`. `TOUCH_RISE_MIN` then **clamped Left's threshold upward**, inverting its own purpose: `rise = 800/2,343,997 = 0.000341` → clamped to 0.005 → `WakeAbsL = 11,719`, 14× the working value.

*How it resolves it.* Two independent guards, either sufficient:

- `fed4TouchAllPadsHwInactive()` gates the rescue on the **hardware** model (`smooth − bench < wakeAbs` on all three). With `SmoothL − BenchL = 2,179,318` vs `wakeAbs 853`, hardware says ACTIVE → rescue blocked. The old code trusted only the software model, which is the one that can be stuck.
- `TOUCH_CAL_MAX_IDLE_DEVIATION_FRAC` (0.10) rejects any per-pad `Idle` move beyond ±10 % of the first boot characterization; `TOUCH_CAL_MAX_RISE_MULT` (2.0) caps threshold growth.

This also closes the nastiest property of the old failure: writing `Idle = Smooth` made the rise fraction exactly 0, so "pads released" returned true and **the rescue never fired again**. The bad calibration silenced its own alarm — the sensor is validated against itself, so any frozen reading is by definition "released" once absorbed.

**6. Stale-benchmark watchdog** — `BenchReset (We may not need it implemented, only for troubleshooting)`

*Why.* A benchmark stranded *below* the true baseline latches its channel active, which is what freezes the benchmark — self-locking, no exit. v1.7.0 called `touch_pad_reset_benchmark()` nowhere, so no recovery path existed anywhere in the codebase. Note the irony of the 3.2.1 port: `fed4TouchApplyThresholds()` deliberately stopped restarting the FSM (*"would destroy drift tracking"*), which correctly fixed NG's bad-boot-seed problem — and in doing so deleted the only path that could ever reset a stranded benchmark. It traded *fails immediately, recoverable* for *survives a day, then fails permanently*.

*How it resolves it.* On `Heartbeat` rows only (never the poke path), if `smooth − bench >= wakeAbs` persists for `FED4_TOUCH_BENCH_STUCK_MS` (5 min), force a per-channel `touch_pad_reset_benchmark()`. The asymmetry makes this safe: stuck-**high** self-heals via the hardware IIR while the channel is inactive; stuck-**low** never does. 43 h of dead Left becomes 5 min.

**7. Bounded pre-sleep release wait** — `ReleaseWait` / `Stuck (We may not need it implemented, only for troubleshooting)`

*Why.* `while (!fed4TouchPadsReleased(...))` had no timeout and no break, and the rescue was one-shot per call. If pads never read released, `waitUntil()` never returns — device alive, logging nothing. This did not trigger in the field log, but it is a real trap and a hang teaches you nothing.

*How it resolves it.* `FED4_TOUCH_RELEASE_WAIT_MS` (5 s) forces a `break` and proceeds to sleep with the timer wake still armed, recording `ReleaseWaitMs`. A hang becomes a logged event.

### Group D — observability

**8. Touch diagnostic CSV** — appended **after** `WakeCount` so existing parsers and mixed-vintage `pd.concat` keep working:

| Columns | Answers |
| --- | --- |
| `ScanPeriodUs`, `MeasUsL/C/R` | Did change 1 land? Is a pad creeping toward the timeout? |
| `TimeoutCount` | Is change 2 firing, and when? |
| `StatusMask`, `IsrChan`, `IsrMask`, `IsrCount` | Change 3 verification — distinguishes "ISR never fired" from "ISR reported wrong" |
| `PeakL`, `PeakC`, `PeakR` | **Per-pad ground truth** — score `Pad` against these to measure attribution accuracy |
| `ConfirmAgreed` | How often confirm abstains (change 4) |
| `ReleaseWaitMs` | ~0 on a healthy device (change 7) |

New row types: `CalReject`, `BenchReset`, `ReleaseWait`, `Stuck`.

**9. Version trackability** — `FED4_FIRMWARE_VERSION_STR = 1.7.0.1` on the display Task-right and footer, in the serial boot line, and in CSV `LibraryVer`. Sketches report `AwakeDrift` / `SleepDrift`.

---

## Known gaps (not fixed in this build)

Change 6 now *recovers* from a stranded benchmark within 5 min, but these three would stop the stranding happening at all. All in `fed4TouchFilterConfig()`.

| Location | Current | Why it matters |
| --- | --- | --- |
| `[FED4_Touch.cpp:193](../../src/FED4_Touch.cpp#L193)` | `noise_thr = 2` | Coefficient 2/8 → the benchmark's noise band is only `0.25 × threshold` = 213 counts, so anything beyond that is chased as a real baseline shift. The displacement that stranded `BenchL` was **1,339 counts**. `noise_thr = 3` gives coefficient 1 — a 4× wider band that would reject it outright. |
| `[FED4_Touch.cpp:195](../../src/FED4_Touch.cpp#L195)` | `smh_lvl = TOUCH_PAD_SMOOTH_OFF` | Smooth *is* raw — zero rejection of a single bad sample. **22 % of pokes** in the field log contaminated another pad's reading; one drove Left to 249,583. |
| `[FED4_Touch.cpp:420](../../src/FED4_Touch.cpp#L420)` | `TOUCH_RISE_MIN = 0.005` | Pinned Left at 0.500 % of baseline while Center/Right got 0.726 %/0.812 %, making Left the weakest link by ~35 %. Also the clamp that produced `WakeAbsL = 11,719`. |

NVS poke-delta calibration remains **WIP** (`begin()` does not auto-load it).

First tracked **test-script** flash on board **v1.7.0**. The Arduino library package stays `1.7.0`; this 4th digit marks the in-lab build that includes the touch-path fixes and the dual-arm drift loggers.

| | |
| --- | --- |
| **Firmware**  | `1.7.0.1` (`FED4_FIRMWARE_VERSION_STR`) |
| **Board** | `1.7.0` |
| **Display** | Task-right + footer: `v1.7.0.1` |
| **CSV** | `LibraryVer=1.7.0.1` |
| **Bump rule** | Next number (`1.7.0.2`) only if `src/` changes |

---

## What this flash is for (test plan)

Pair of arms that write the **same** `_T.CSV` schema and differ only in `Mode` / Task name. If Awake stays healthy while Sleep dies, the fault is light-sleep / benchmark / latch — not the pad.

Rebuild the **library** after confirming `FED4_ENABLE_TOUCH_LOG` is `1` in `[src/FED4.h](../../src/FED4.h)`. An `.ino` `#define` does not reach library sources.

### Arm A — Awake touch drift

| | |
| --- | --- |
| Sketch | `[examples/3_Troubleshooting/TouchDriftLog_Awake/](../../examples/3_Troubleshooting/TouchDriftLog_Awake/)` |
| Task on display / CSV `Program` | **AwakeDrift** |
| `touchLogMode` | `Awake` |
| Sleep | Never — CPU stays up |
| Heartbeat | 1 Hz `_T.CSV` row |
| Pokes | Software `(smooth − idle)` vs `wakeAbs`; logged on release |

**Check:**

- [ ] Display: `Task: AwakeDrift` and `v1.7.0.1`
- [ ] Serial boot line includes `Firmware 1.7.0.1` and `task AwakeDrift`
- [ ] `_T.CSV` created (`Mode=Awake`, `LibraryVer=1.7.0.1`)
- [ ] Left / Center / Right pokes increment the matching counter and indicator
- [ ] `PeakSmooth` / `PokeDuration` present on `Poke` rows
- [ ] `LatchPad` is 0 (no ISR latch on this arm)
- [ ] Overnight: `Idle` stable, `Bench` may track; no frozen Smooth/Bench on all pads

### Arm B — Sleep touch drift

| | |
| --- | --- |
| Sketch | `[examples/3_Troubleshooting/TouchDriftLog_Sleep/](../../examples/3_Troubleshooting/TouchDriftLog_Sleep/)` |
| Task on display / CSV `Program` | **SleepDrift** |
| `touchLogMode` | `LightSleep` |
| Sleep | `waitUntil(60)` — production-shaped light sleep + touch wake |
| Heartbeat | Timer wake (~60 s) |
| Left poke | Feeds (same as BasicFED4) |

**Check:**

- [ ] Display: `Task: SleepDrift` and `v1.7.0.1`
- [ ] Serial boot line includes `Firmware 1.7.0.1` and `task SleepDrift`
- [ ] `_T.CSV` created (`Mode=LightSleep`, `LibraryVer=1.7.0.1`)
- [ ] Touch wake identifies the correct pad (`Pad` matches physical well; `LatchPad` / `ConfirmPad` / `ConfirmAgreed`)
- [ ] `TouchMiss` stays rare (touch wake with no pad = primary failure signature)
- [ ] Pre-sleep hang does not last forever (`ReleaseWait` / `Stuck` if slow)
- [ ] Overnight / multi-day cage: pokes still detected; no all-pad Smooth/Bench freeze
- [ ] If Idle would jump wildly, `CalReject` instead of absorbing a loaded pad
- [ ] Stale-low benchmark recovers via `BenchReset` (after `FED4_TOUCH_BENCH_STUCK_MS`)

### Analysis

```text
python extras/analysis/fed4_touch_analysis.py /path/to/sd_dumps -o out/
```

| Observation | Conclusion |
| --- | --- |
| Awake healthy, Sleep dying | Light-sleep / benchmark / latch — not the pad |
| `Idle` flat, `Bench` rising, pokes dying  | Hardware tracker absorbed occupant/drift |
| `Idle` jumps at `Rechar`, pokes die after | Recalibrated with a mouse nearby (`CalReject` should block this) |
| High `TouchMiss` | Identification failing, not detection |
| `TimeoutCount` climbing, Smooth frozen | FSM measurement timeout — should resume in this build |

Full poke/touch background: `[docs/wiki/Poke-Functionality.md](../wiki/Poke-Functionality.md)`.

---

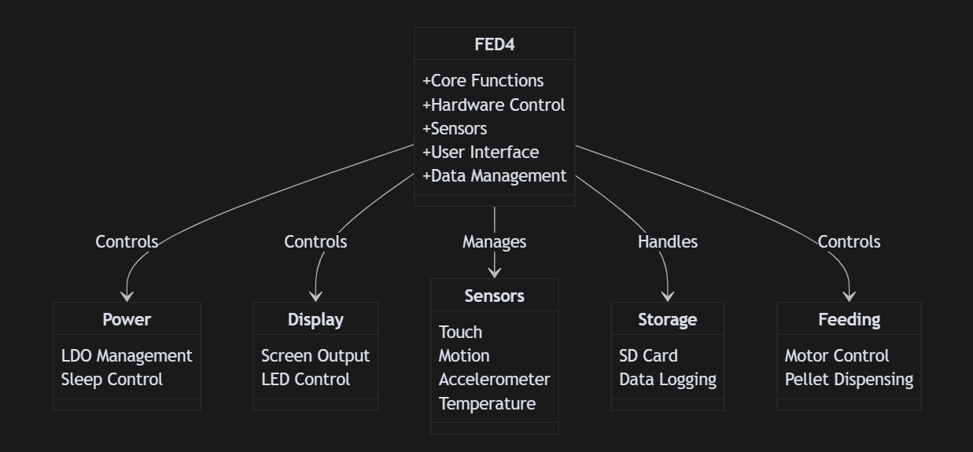
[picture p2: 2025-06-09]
extras/images/FED4_overview.png

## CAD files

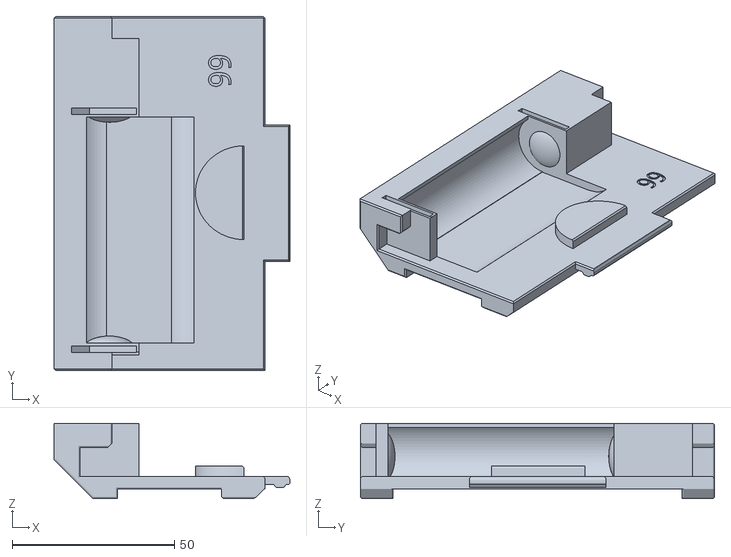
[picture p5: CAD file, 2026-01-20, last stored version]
extras/3D_designs/FED4_010126_Base_chamfer.stl
72.7 x 109.1 x 23.2

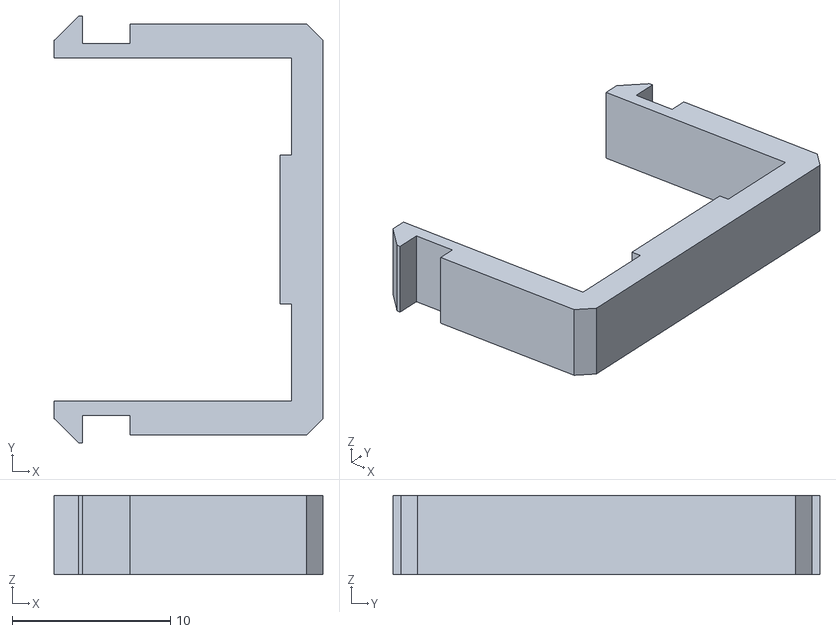
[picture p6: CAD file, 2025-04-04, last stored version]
extras/3D_designs_Apr2025/FED4_031725_nose.stl
17.0 x 27.0 x 5.00

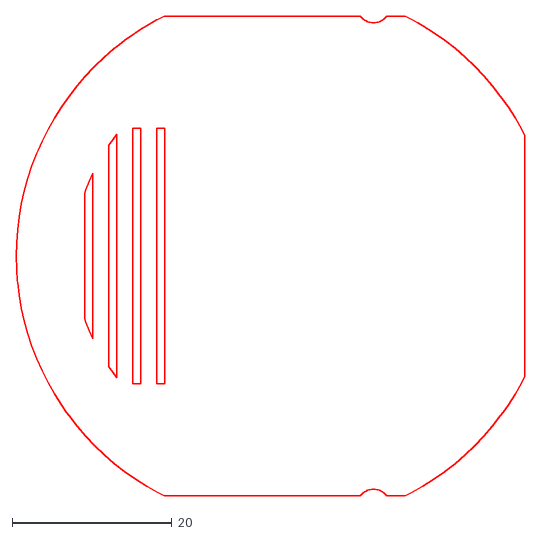
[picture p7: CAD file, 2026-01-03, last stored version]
extras/laser_cutting/FED4_010126_HopperLid.dxf
63.6 x 60.0

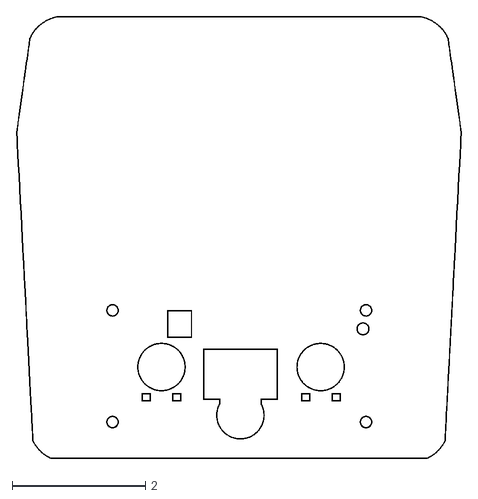
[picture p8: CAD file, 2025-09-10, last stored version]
extras/LaserCutting/FED4_laserfrontNoLogo091025.dxf
6.68 x 6.63

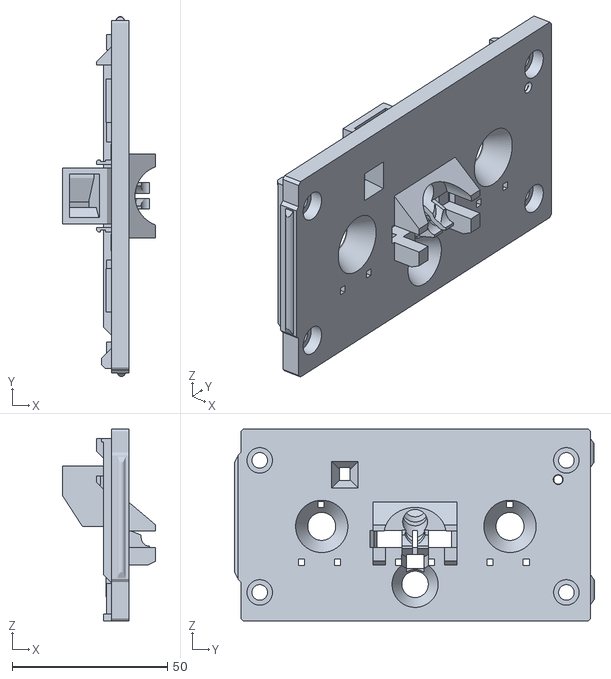
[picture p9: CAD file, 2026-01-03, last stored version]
extras/3D_designs/FED4_010126_Front.stl
30.0 x 115.9 x 61.8

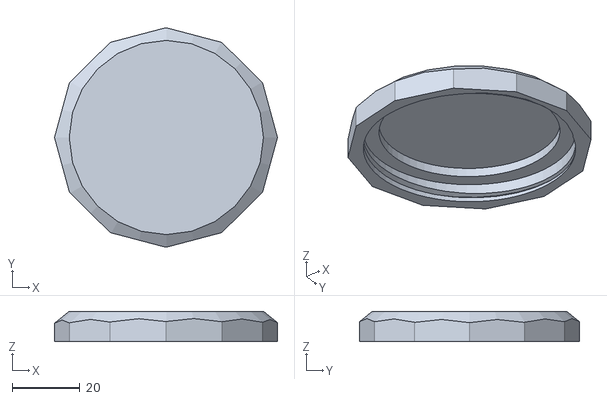
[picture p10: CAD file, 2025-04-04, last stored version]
extras/3D_designs_Apr2025/FED4_031725_lid.stl
66.0 x 65.0 x 9.00

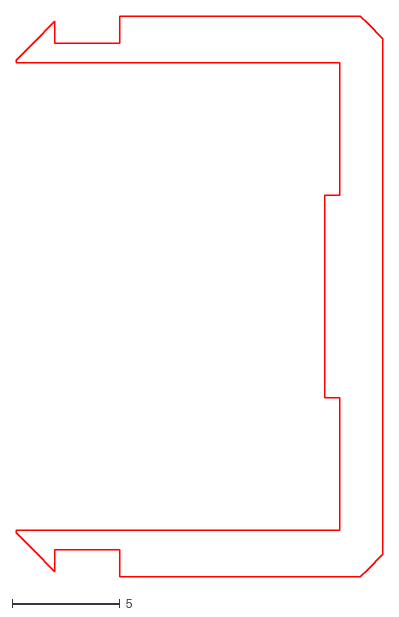
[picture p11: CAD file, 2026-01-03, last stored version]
extras/laser_cutting/FED4_010126_Nose.dxf
17.0 x 26.0

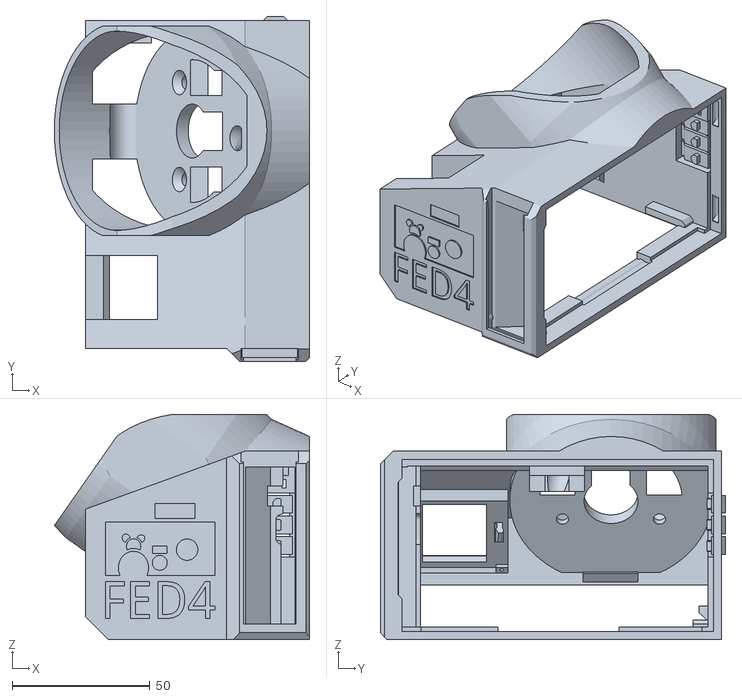
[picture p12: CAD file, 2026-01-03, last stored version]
extras/3D_designs/FED4_010126_Housing.stl
92.7 x 125.2 x 81.7

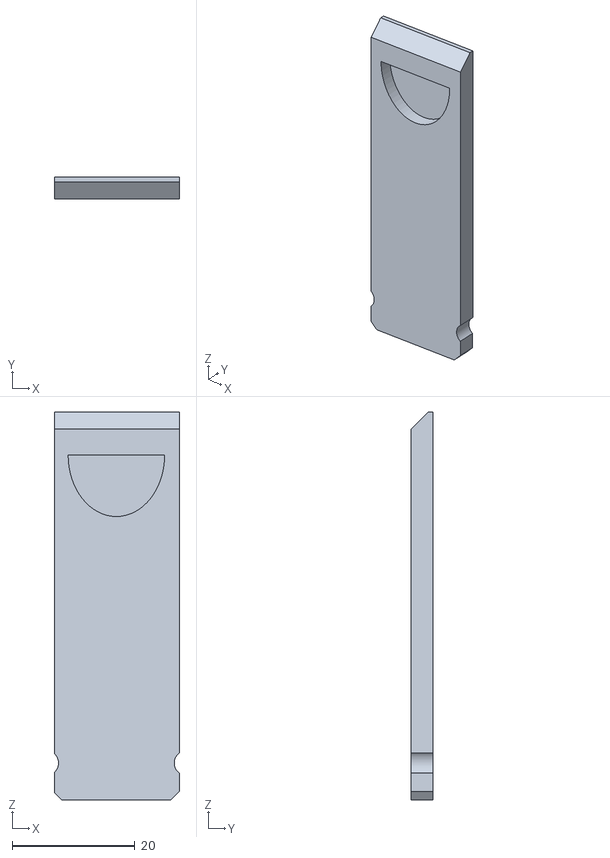
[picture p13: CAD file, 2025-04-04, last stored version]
extras/3D_designs_Apr2025/FED4_031725_sidecover.stl
20.4 x 3.60 x 63.1

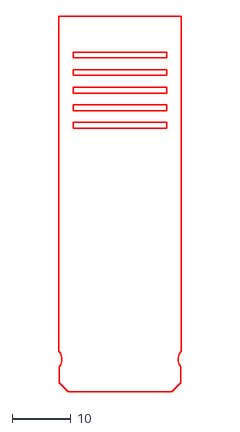
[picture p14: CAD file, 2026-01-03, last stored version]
extras/laser_cutting/FED4_010126_SideDoor.dxf
21.0 x 64.1

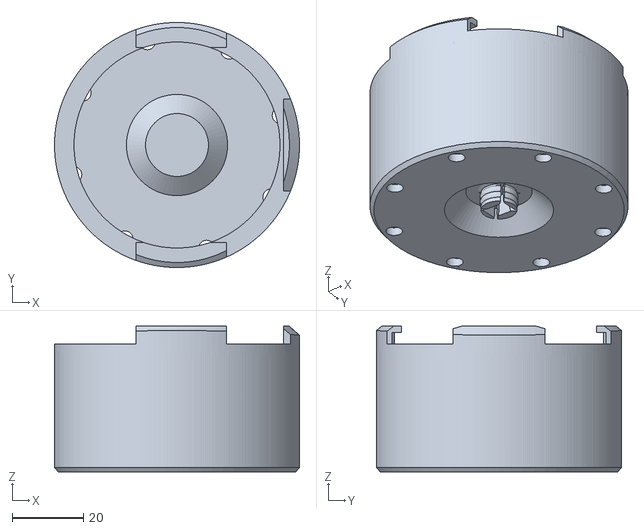
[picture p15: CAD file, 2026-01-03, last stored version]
extras/3D_designs/FED4_010126_Hopper.stl
69.0 x 69.0 x 41.0

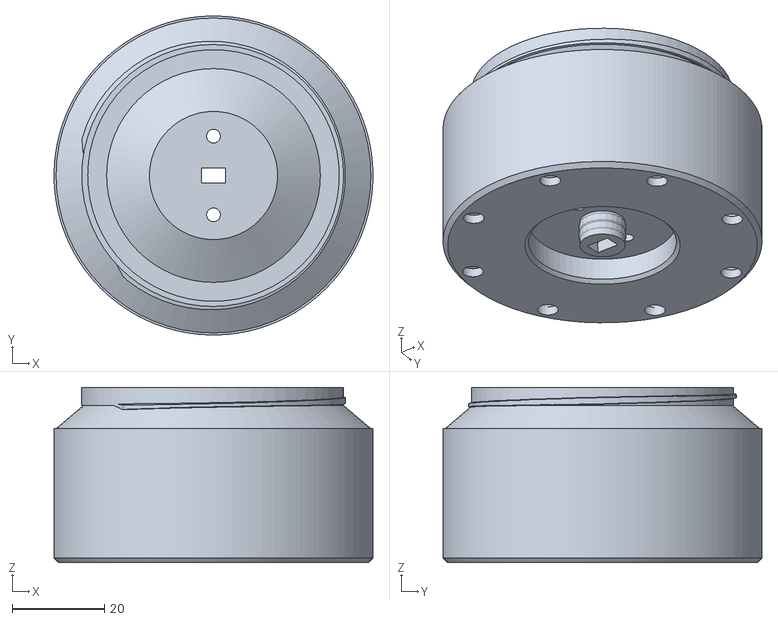
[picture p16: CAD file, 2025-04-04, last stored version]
extras/3D_designs_Apr2025/FED4_031725_hopper.stl
69.0 x 69.0 x 38.0

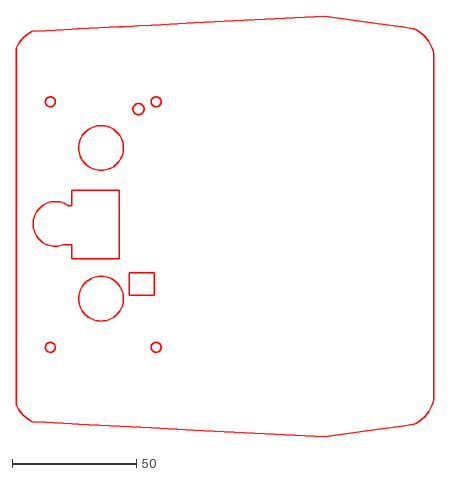
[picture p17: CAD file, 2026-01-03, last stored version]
extras/laser_cutting/FED4_010126_Front.dxf
168.0 x 169.2

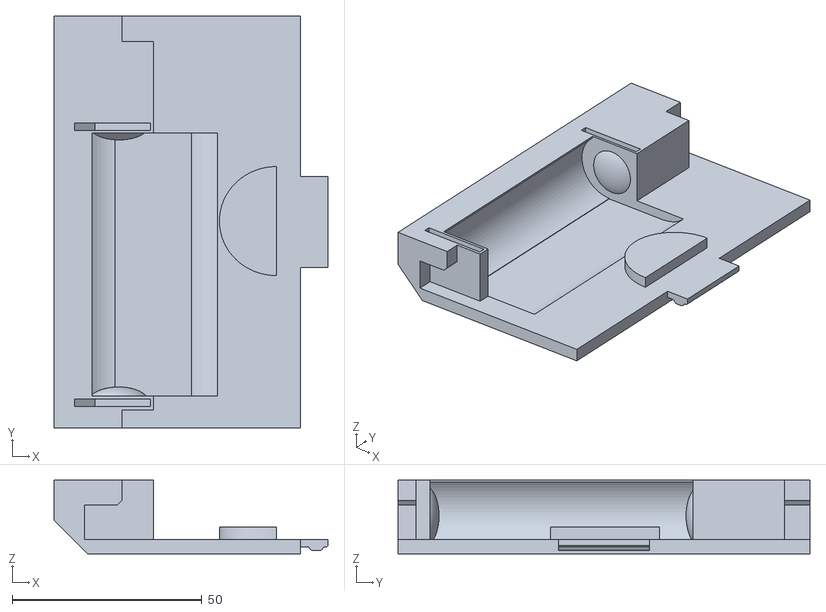
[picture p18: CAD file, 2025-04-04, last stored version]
extras/3D_designs_Apr2025/FED4_031725_bottom.stl
72.2 x 108.5 x 19.4

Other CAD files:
extras/3D_designs/FED4_010126_Base.stl
extras/3D_designs_Apr2025/FED4_031725_housing.stl
extras/3D_designs_Apr2025/FED4_031725_front.stl

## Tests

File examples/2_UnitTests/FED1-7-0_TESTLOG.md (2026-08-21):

# FED v1.7 Hardware Examples Test Log

## Notes for v1.7.1

- Re-think SD card and display power rails; sharing 3.3V2 means a lot of other stuff becomes active w/ SD card
- **MAX98357A on 3.3V2:** `I_Q` ~2.4 mA only when **SD HIGH + I2S clocks** (active). **SleepModes** drives `EXP_AMP_SD` LOW → shutdown **~0.6 µA** (`I_SHDN`). Standby (SD HIGH, no BCLK) = **~340 µA**. Consider dedicated amp rail for audio-active sketches (v1.7.1)
- **TCA4307 on 3.3V2:** ~2.5 mA `I_CC` typ to isolate RTC I2C — primary motivation to drop isolator or gate EN in v1.7.1 (RTC on main bus or new chip)
- **GP1A57HR photogate on 3.3V2:** IR LED hard-wired to rail via **1 kΩ** → **~2.5–3.0 mA per mounted gate** whenever PSV2 on; GPIO only reads open-collector output. Gate LED bias or separate PG rail for light-sleep savings (v1.7.1)
- Add more separation between RESET/BOOT buttons

## Power Profile

Baseline state model from `[FED4-SleepModes.ino](FED4-SleepModes/FED4-SleepModes.ino)` — **5 s light sleep → brief awake → 5 s deep sleep**, repeating.

### Measured (VBATT)

Ammeter on pack; SleepModes sketch unless noted. Battery life = capacity ÷ current (constant-mode, ideal — no self-discharge or Peukert).

| Mode | Measured | 3300 mAh | 6600 mAh | 10050 mAh |
| --- | --- | --- | --- | --- |
| **Power switch off** | 4.5 µA | ~84 yr | ~167 yr  | ~255 yr |
| **Startup / active** | 52.42 mA | 2.6 d | 5.2 d | 8.0 d |
| **Light sleep** | 6.82 mA  | 20 d | 40 d | 61 d |
| **Deep sleep** | 1.38 mA  | 3.3 mo | 6.6 mo | 10 mo |
| **SleepModes avg**¹  | ~4.1 mA  | 34 d | 67 d | 102 d |

¹ Measured 50/50 duty: (6.82 + 1.38) / 2 ≈ 4.1 mA; excludes short awake SPI bursts (~52 mA).

### Measured (VBATT) — v1.7.1 Mods

Ammeter on pack; SleepModes sketch unless noted. Battery life = capacity ÷ current (constant-mode, ideal — no self-discharge or Peukert).

**Mod 1:** Removed I2C isolator (TCA4307), tied I2C_2 to I2C, removed I2C2 pull-ups; DS3231 RTC tied to always-on **3.3 V** (main I2C bus).

| Mode | Measured | 3300 mAh | 6600 mAh | 10050 mAh |
| --- | --- | --- | --- | --- |
| **Startup / active** | 50.24 mA | 2.7 d | 5.5 d | 8.3 d |
| **Light sleep** | 4.92 mA  | 28 d | 56 d | 85 d |
| **Deep sleep** | 1.48 mA  | 3.1 mo | 6.2 mo | 9.5 mo |
| **SleepModes avg**¹  | ~3.2 mA  | 43 d | 86 d | 131 d |

¹ Measured 50/50 duty: (4.92 + 1.48) / 2 ≈ 3.2 mA; excludes short awake SPI bursts (~50 mA).

**vs v1.7 (stock):** Light sleep **−1.9 mA** (6.82 → 4.92) — consistent with removing TCA4307 ~2.5 mA `I_CC` while PSV2 remains on. Deep sleep **+0.1 mA** (1.38 → 1.48); within measurement noise. RTC on 3.3 V eliminates isolator back-power when PSV2 is off.

**Light sleep budget — reconciled (bench: 1× GP1A57HR mounted on 3.3V2, 1 kΩ LED resistor):**

| Bucket | Stock v1.7 (~6.82 mA) | v1.7.1 Mod 1 (~4.92 mA) |
| --- | --- | --- |
| **ESP32-S3** light sleep + touch wake | ~1.1 mA | ~1.1 mA |
| **Always-on 3.3 V** (MCP, sensors shutdown, MIP, RTC¹) | ~0.5–0.8 mA | ~0.5–0.8 mA |
| **TCA4307** (`I_CC`, PSV2 on) | ~2.5 mA | 0 (removed) |
| **GP1A57HR** ×1 (3.3V2, LED always on) | **~2.5–3.0 mA** | **~2.5–3.0 mA** |
| Amp + other PSV2 leakage | ~0.1 mA | ~0.1 mA |
| **Sum (typ)** | **~6.7–7.5 mA** | **~4.2–5.0 mA** |

¹ v1.7.1 Mod 1: DS3231 on always-on 3.3 V (~100–200 µA included in always-on bucket). Stock: RTC on PSV2 behind TCA4307.

PSV2 stays **on** during light sleep → photogate IR LED draws whenever the rail is enabled. Driving photogate GPIO LOW does not cut LED current (LED tied directly to 3.3V2).

**Deep sleep PSV2-off anomaly (bench, SleepModes):**

| Condition | Deep sleep VBATT | Notes |
| --- | --- | --- |
| PSV2 **off** (intended) | **~17 mA** observed | ~+10 mA vs keeping PSV2 on — not SD-card-specific  |
| PSV2 **on** during deep sleep | ~light sleep + **~1 mA** | ESP32 mode delta only; 3.3V2 loads behave normally |
| SDIO teardown alone | No improvement | Rules out SD socket back-power as sole cause |

Turning **PSV2 off** should remove ~2.5 mA (TCA4307, stock) plus small PSV2 leakage and yield ~1.4 mA; a bench solder issue once showed ~17 mA instead. Likely **GPIO/I2C back-power into the unpowered 3.3V2 domain**:

| Path | Always-on source | PSV2 load at risk |
| --- | --- | --- |
| Photogate GPIO 14/17/18/37 | ESP32 I/O (INPUT_PULLUP in production sketches) | PG LED + receiver front-ends on 3.3V2 |
| I2S GPIO 40/41/42 | ESP32 I/O after audio init | MAX98357A on 3.3V2 |
| Main I2C SDA/SCL pull-ups | MCP + sensors on 3.3 V | **TCA4307 + DS3231** when isolator VCC off |
| MCP EXP_AMP_SD / haptic / sol LOW | MCP23017 on 3.3 V | PSV2 peripherals with VDD off |

`FED4-SleepModes` now drives photogate + I2S lines **LOW** and quiesces SDIO before `PSV2_OFF()` — retest deep sleep. Remaining suspect if still high: **main I2C → TCA4307** (architectural; v1.7.1 RTC bus change).

**PSV2 light vs deep delta (6.82 − 1.38 ≈ 5.4 mA) — reconciled (PSV2 off working correctly):**

SleepModes holds **`EXP_AMP_SD` LOW** before sleep → MAX98357A in **shutdown** (~0.6 µA), not 2.4 mA active `I_Q`.

| 3.3V2 load (PSV2 on, light sleep) | Typ current | Deep sleep (PSV2 off) |
| --- | --- | --- |
| **TCA4307** I2C isolator (`I_CC`) | **~2.5 mA** (stock) | 0 |
| **GP1A57HR** photogate ×1 (1 kΩ LED)  | **~2.5–3.0 mA** | 0 |
| **MAX98357A** amp (`EXP_AMP_SD` LOW)  | **~0.6 µA** | 0 |
| DS3231 RTC (stock PSV2) + SD/sol/haptic | ~0.1–0.3 mA | 0 |
| **PSV2 subtotal** (1 PG mounted) | **~5.1–5.8 mA** (stock) / **~2.6–3.3 mA** (Mod 1) | 0 |

Plus **ESP32-S3** light sleep + touch (**~1.1 mA**) and **always-on 3.3 V** loads (MCP, sensors, MIP ≈ **0.5–0.8 mA**) → stock **~6.8 mA** and Mod 1 **~4.9 mA** light sleep match measured values. Deep sleep **~1.4 mA** is ESP32 deep sleep + always-on domain (PSV2 off removes TCA4307 + photogate LED + other 3.3V2 loads).

### TCA4307DGKR — datasheet (§5.5 POWER SUPPLY, typ @ 25 °C)

Isolates main I2C from **SDA_2/SCL_2** (RTC on isolated segment). On **3.3V2** with PSV2.

| Parameter | Symbol | Typ | Max | SleepModes mapping |
| --- | --- | --- | --- | --- |
| Supply current | `I_CC` | **2.5 mA** | 4.5 mA | EN enabled, bus idle (PSV2 on) |
| Shutdown current | `I_SD` | **10 µA**  | 30 µA  | EN = 0 (not used while RTC isolation required) |

### MAX98357A — datasheet (Electrical Characteristics, typ @ 25 °C)

On **3.3V2** with PSV2. `EXP_AMP_SD` (SD_MODE) via MCP23017: **LOW = shutdown**, **HIGH = channel select / active**.

| Parameter | Symbol | Typ | Max | SleepModes mapping |
| --- | --- | --- | --- | --- |
| Quiescent current | `I_DD`  | **2.4 mA** | 2.85 mA | SD HIGH + I2S clocks (active — Demo/Speaker sketches) |
| Standby current  | `I_STNDBY` | **340 µA** | 400 µA | SD HIGH, BCLK stopped (not used in SleepModes) |
| Shutdown current | `I_SHDN` | **0.6 µA** | 2 µA | **`EXP_AMP_SD` LOW** — light/deep prep in SleepModes |
| Turn-on time | `t_ON` | **7 ms** | 7.5 ms | After SD HIGH from shutdown (not ns — separate from I2S setup/hold) |

### GP1A57HR photointerrupter — datasheet (Electro-optical, typ @ 25 °C)

Sharp **GP1A57HR** on **3.3V2** (PSV2). IR LED tied **directly to 3.3V2** through **1 kΩ** series resistor (always on when PSV2 on). ESP32 GPIO (14/17/18/37) reads open-collector output only.

| Parameter | Symbol | Typ @ 5 V (datasheet) | On FED4 @ 3.3V2 (1 kΩ LED) | SleepModes mapping |
| --- | --- | --- | --- | --- |
| Forward current | `I_F` | 7 mA (test condition) | **~(3.3 − 1.1) / 1k ≈ 2.2 mA** | LED always on when PSV2 on |
| Supply current (output high) | `I_CCH` | 0.7 mA | **~0.3–0.5 mA** (scaled) | Detector IC, beam clear |
| Supply current (output low) | `I_CCL` | 1.7 mA | **~0.5–0.8 mA** (scaled) | Detector IC, beam blocked |
| **Per mounted gate** | — | ~8 mA @ 5 V / 7 mA `I_F` | **~2.5–3.0 mA** | **1× mounted on bench DUT** |

Four populated gates at the same bias → **~10–12 mA** additional PSV2 load. `PSV2_OFF()` in deep sleep removes photogate current entirely.

### Kyocera TN0216 LCD — datasheet (§6-1, 25 °C)

Panel logic on **3.3 V** (`V_DD` typ 3.3 V). Backlight (`EXP_DISPLAY_LED`) is separate MCP drive.

| Parameter | Symbol | Typ | Max | SleepModes mapping |
| --- | --- | --- | --- | --- |
| Operating current | `I_DD_opr` | **22 µA**  | 45 µA  | RST LOW — panel ON (light sleep, awake between refreshes) |
| Standby current | `I_DD_stb` | **1.5 µA** | 5.5 µA | RST HIGH — panel blanked (deep sleep) |
| Input leak | `I_IN` | 5 nA | 20 nA  | GPIO/SPI idle |

**Implication:** Panel silicon is negligible (`I_DD` ≈ 22 µA). In **SleepModes** light sleep with **PSV2 on**, dominant loads are **TCA4307 ~2.5 mA (stock)** and **~2.5–3.0 mA per GP1A57HR** (1 kΩ LED on 3.3V2) — not the amp (`EXP_AMP_SD` LOW → ~0.6 µA). Deep sleep savings come from **`PSV2_OFF()`** removing isolator, photogate LED, and other 3.3V2 peripherals.

### Total current by mode (est.)

| Mode | Low | Typical | High | Dominant loads |
| --- | --- | --- | --- | --- |
| **Awake** (active — SPI refresh, I2C init) | 45 mA  | **~65 mA** | 90 mA  | ESP32-S3 CPU + SPI display; 3.3V2 idle bias |
| **Light sleep** (5 s, VCOM keepalive) | 3 mA | **~5 mA** | 8 mA | ESP32 ~1.1 mA + touch; PSV2 on — **TCA4307 ~2.5 mA** (stock) + **GP1A57HR ~2.5–3 mA/gate** |
| **Deep sleep** (5 s, panel blanked) | 0.1 mA | **~0.3 mA**  | 0.6 mA | ESP32 deep sleep; **PSV2 off** (panel `I_DD_stb` ≈ 1.5 µA) |
| **SleepModes avg**¹ | 2 mA | **~5–10 mA** | 15 mA  | ~50 % light / ~50 % deep + short awake bursts |

¹ Time-weighted over one cycle (≈1 s awake @ 65 mA, 5 s light @ 5 mA, 5 s deep @ 0.3 mA) → **~7–9 mA** average pack draw. Dominated by light-sleep phase unless PSV2 is cut or display maintenance is reduced.

**Assumptions:** ESP32-S3 @ 240 MHz, WiFi/BT off, USB unplugged; **light sleep + touch ≈ 1.1 mA**. **TCA4307** `I_CC` ≈ **2.5 mA** when PSV2 on (stock). **GP1A57HR:** **~2.5–3.0 mA** per gate on 3.3V2 (1 kΩ LED, rail-tied). **MAX98357A:** ~**0.6 µA** in SleepModes (`EXP_AMP_SD` LOW). Kyocera `I_DD` ≈ 22 µA. Bench DUT: **1 photogate mounted**.

### SleepModes cycle (one iteration)

| Phase | Duration (nom.) | ESP32 mode |
| --- | --- | --- |
| Awake — draw status, sensor init | ~0.5–2 s (boot longer) | Active |
| Light sleep — VCOM keepalive | 5 s | `esp_light_sleep` (500 ms timer chunks + touch wake) |
| Awake — draw status | ~0.1–0.5 s | Active (SPI display refresh) |
| Deep sleep | 5 s | `esp_deep_sleep` (timer wake, reboot) |

Effective duty cycle ≈ **50 % light sleep / 50 % deep sleep**, plus short active windows for display + I2C.

### Device states by phase

| Device / rail | Awake (active) | Light sleep | Deep sleep | Est. (awake / light / deep) |
| --- | --- | --- | --- | --- |
| **ESP32-S3** | Active (default CPU clk) | Light sleep; touch FSM armed | Deep sleep | 45–80 mA / **~1.1 mA** / 15–50 µA |
| **3.3V2 `EXP_PSV2_EN`** | ON (LOW) | ON | **OFF** (HIGH) | — |
| **3.3V3 `EXP_PSV3_EN`** | ON at boot; OFF before sleep | OFF | OFF | — |
| **MCP23017T** (I2C `0x20`) | I2C active | Idle; outputs LOW | Idle; holds PSV2/PSV3 OFF | 0.3–1 mA / 1–50 µA / 1 µA |
| **Kyocera MIP** (panel `I_DD` only) | RST LOW; operating | RST LOW; operating | RST HIGH; standby | 22 µA / 22 µA / 1.5 µA (typ) |
| **LIS2DH12TR** | 50 Hz HR mode | Power-down | Power-down | 0.1–0.2 mA / 2 µA / 2 µA |
| **BME680** | Idle (heater off between reads) | Sleep | Sleep | 0.9 mA / 0.2 µA / 0.2 µA |
| **VEML7700** | Enabled | `enable(false)` | `enable(false)` | 60–100 µA / 0.5 µA / 0.5 µA |
| **VL53L1X** | `stopRanging()` after use | `stopRanging()` | `stopRanging()` | 50 µA–1.4 mA² / 50–100 µA / 50–100 µA |
| **EKMB1107112 PIR** | GPIO input | GPIO input | GPIO input | ~6 µA (all phases) |
| **TCA4307** I2C isolator (RTC segment) | EN on; PSV2 on | EN on; PSV2 on | **PSV2 off** | ~2.5 mA / ~2.5 mA / 0 |
| **GP1A57HR photogate** (GPIO 14/17/18/37) | 3.3V2; LED on rail (1 kΩ) | 3.3V2; **LED on** (PSV2 on)  | **PSV2 off** — LED off | — / **~2.5–3 mA/gate** / 0 |
| **MAX98357A amp** (I2S, `EXP_AMP_SD`)  | PSV2 on; SD HIGH (audio) | PSV2 on; **SD LOW** (shutdown) | **PSV2 off** | ~2.4 mA / **~0.6 µA** / 0 |
| **DS3231 RTC** | On isolated I2C (stock) | On isolated I2C (stock) | **Unpowered** (stock) | ~0.1–0.2 mA / ~0.1–0.2 mA / 0 |
| **3.3V2 domain** (SD, haptic, sol) | Rail on; MCP outputs LOW | Rail on | **Rail off** | ~0.1 mA / ~0.1 mA / 0 |
| **RGB strip + STATUS_LED** | OFF | OFF | OFF | 0 |
| **Motor ULN2003LV** | Pins LOW | Pins LOW | Pins LOW | <10 µA |
| **MAX17048** | Active on VBATT | Active on VBATT | Active on VBATT | ~50 µA (all phases) |
| **→ Subtotal (est.)** | **~45–90 mA** | **~3–8 mA** | **~0.1–0.6 mA** | **~45–90 mA / ~3–8 mA / ~0.1–0.6 mA** |

² VL53L1X draw highly state-dependent without XSHUT; confirm `stopRanging()` standby on hardware.

### Open power items (v1.7.1)

| Item | Notes |
| --- | --- |
| **Measured SleepModes totals** | Done — see **Measured (VBATT)** table above |
| **CPU 80 MHz** | `setCpuFrequencyMhz(80)` in awake windows only? Estimate savings vs display + I2C dominate |
| **USB detection** | No `USB.connected()` on ESP32 core 3.2.1; options: `Serial` DTR (bench only), VBUS GPIO if routed, or skip Serial wait on battery (current SleepModes approach) |
| **Display in deep sleep** | Datasheet `I_DD_stb` ≈ 1.5 µA — measured 1.38 mA pack is almost entirely non-panel loads |
| **PSV2 off during deep sleep** | Bench saw ~17 mA until PSV2 left on; suspect I2C/GPIO back-power into 3.3V2 — SleepModes quiesces PG + I2S + SDIO before rail off |
| **PSV2 on during light sleep** | **~2.5–3 mA/gate** GP1A57HR (1 kΩ LED on 3.3V2) + **~2.5 mA** TCA4307 (stock); Mod 1 removes isolator — gate LED still on while PSV2 on |
| **MCP23017T baseline** | On always-on 3.3V in all phases — measure quiescent I2C expander draw; holds rail enables during deep sleep |

## v1.7 Power Rails

TPS22917 load switches: **LOW = rail ON**, **HIGH = rail OFF** (`EXP_PSV2_EN` = MCP pin 13, `EXP_PSV3_EN` = MCP pin 12).

### VBATT (LiPo)

| Peripheral | Notes |
| --- | --- |
| ULN2003LV motor driver (GPIO 38/45/46/47) | VBATT; hold motor pins LOW when idle |
| MAX17048 fuel gauge (I2C `0x36`) | VBATT; always powered on battery |

### 3.3V (always on)

| Peripheral | Notes |
| --- | --- |
| MCP23017T GPIO expander (I2C `0x20`) | Always powered; drives PSV2/PSV3, display RST/LED, solenoids, haptic, amp SD — cannot rail-gate |
| VL53L1X ToF (I2C `0x29`) | Register shutdown for sleep |
| VEML7700 lux (I2C `0x10`) | `enable(false)` for sleep |
| EKMB1107112 PIR (GPIO 10) | Always powered; GPIO input |
| BME680 (I2C `0x76`) | Sleep mode + gas heater off |
| LIS2DH12TR accel (I2C `0x19`) | Power-down data rate |
| Kyocera MIP display (SPI, MCP RST/LED, GPIO VCOM/CS) | Always on 3.3 V; `I_DD_opr` 22 µA typ / `I_DD_stb` 1.5 µA typ (§6-1); VCOM toggle when ON |

### 3.3V2 — `EXP_PSV2_EN`

| Peripheral | Notes |
| --- | --- |
| DS3231 RTC (I2C `0x68`) | Rail-gated |
| TCA4307DGKR I2C switch (SDA_2/SCL_2 → RTC) | Rail-gated; **`I_CC` typ 2.5 mA** when EN on (isolator always on with PSV2) |
| Haptic motor (`EXP_HAPTIC`) | MCP + rail |
| Speaker amplifier (`EXP_AMP_SD`) | MCP SD + rail; **`I_SHDN` ~0.6 µA** (SD LOW) / **`I_Q` ~2.4 mA** (SD HIGH + I2S) |
| SD card (SPI CS GPIO 48) | Rail-gated |
| Photogate GP1A57HR (GPIO 14/17/18/37) | Rail-gated; **IR LED → 3.3V2 via 1 kΩ** (~2.2 mA) + detector (~0.3–0.8 mA) ≈ **2.5–3 mA/gate** |
| Solenoid driver (`EXP_SOL_1/2`) | MCP + rail |

### 3.3V3 — `EXP_PSV3_EN`

| Peripheral | Notes |
| --- | --- |
| `RGB_STRIP` net and front RGB LEDs (GPIO 36) | Rail-gated |

---

| SKETCH | PASS | FUNCTIONS | NOTES |
| --- | --- | --- | --- |
| `FED4-Accel-Adafruit.ino` | ✓ | LIS3DH accelerometer, main I2C bus, serial accel readout | |
| `FED4-Accel.ino` | deferred | LIS3DH accelerometer, MIP display, tilt-controlled ball demo | Duplicate functionality |
| `FED4-Battery-Fuel-Guage.ino` | ✓ | MAX17048 fuel gauge, main I2C bus, voltage/percent monitoring | Passed; see note. Gauge on VBATT (not 3.3V). With USB and no LiPo, VBATT ~4.2V (MCP73831 + 100µF cap) — valid voltage/`isDeviceReady()`, invalid SOC, ~−4%/hr drain. USB removed: VBATT falls to ~1.5V then cap bleed. MCP73831 STAT pulsing = no pack. Misleading readings are a bench-only USB/no-pack artifact; off VBUS, normal pack operation should be fine. Confirm with real battery. |
| `FED4-Color-Chase-TouchPads-PhotoGate.ino` | deferred | Front RGB strip, touch pads, center photogate, I2S speaker, MCP power rails | Duplicate functionality |
| `FED4-SleepModes.ino` | | Light/deep sleep alternation, VCOM keepalive, sensor shutdown, PSV2/PSV3 rails, touch wake | Requires USB CDC On Boot; replaces FED4-DeepSleep |
| `FED4-VCOM-LEDC-Light-Sleep.ino` | ✓ | Kyocera VCOM via LEDC PWM through `esp_light_sleep` (no CPU toggle chunks) | Passed. Scope: ~502 ms period (~2 Hz) continues awake and in 10 s light sleep. Needs `LEDC_SLEEP_MODE_KEEP_ALIVE` + `LEDC_USE_RC_FAST_CLK` + `gpio_sleep_sel_dis` + `ESP_PD_DOMAIN_RC_FAST` ON. USB CDC On Boot. |
| `FED4-Demo-Hardware.ino` | ✓ | Full hardware sweep: MIP dashboard, env/lux/tof/accel/RTC/battery, photogates, touch+strip, PIR INT, buttons | Requires USB CDC On Boot; motor excluded |
| `FED4-Display-Standalone.ino` | ✓ | Kyocera MIP display, SPI, MCP reset/backlight, PSV2/PSV3 rails | |
| `FED4-Display.ino` | skipped  | Kyocera MIP display via FED4 library, SPI, MCP backlight toggle | Refers to old hardware |
| `FED4-Haptic.ino` | ✓ | Haptic motor, MCP23017, PSV2 power rail | |
| `FED4-LED-Position-Test.ino` | deferred | Front 8-LED strip index mapping, per-pixel colors, left/center/right groups | Requires refactoring; duplicates FED4-LEDs-Front.ino |
| `FED4-LEDs-Front.ino` | ✓ | Front RGB strip, MCP23017 PSV3, three buttons, LED animations | |
| `FED4-LUX.ino` | ✓ | VEML7700 ambient light sensor, main I2C bus, lux readout | |
| `FED4-Mario-SFX.ino` | deferred | I2S speaker via FED4 library, Mario-style sound effects | Duplicate functionality |
| `FED4-Motor.ino` | ✓ | 4-wire stepper motor (pins 38/45/46/47), forward/reverse rotation | See Stepper() pin order (IN1,IN3,IN2,IN4) and 2048 steps/rev for 28BYJ-48 — updated in sketch and library. |
| `FED4-PhotoGates.ino` | ✓ | Four photogate GPIO inputs (center, left, right, pellet detector) | Partial: left/right nose poke untested; will mount test components to validate later. |
| `FED4-PIR-Sensor.ino` | ✓ | PIR motion sensor GPIO input, status LED mirrors motion level | |
| `FED4-RTC.ino` | ✓ | DS3231 RTC, main I2C via PSV2/TCA4307, date/time readout | |
| `FED4-SD-Card.ino` | ✓ | SD card over SPI, mount, directory listing, read/write | |
| `FED4-Submodule-SeeedStudioSense.ino` | | TRRS TRIG+UART Sense master: senseSyncTime + senseTrigPulse | Companion: `examples/3_Submodules/SeeedStudioSense/`; TRIG=TRRS2/GPIO5→Sense GPIO1, DATA=TRRS3/GPIO6→Sense GPIO2 |
| `FED4-Speaker-with-SD.ino` | deferred | I2S amplifier, SD card MP3 playback, buttons, MCP PSV2/amp enable | Special functionality; requires MP3 file (largely software dev) |
| `FED4-Speaker.ino` | ✓ | I2S amplifier, MCP PSV2/amp enable, buttons, generated tones | |
| `FED4-Solenoids.ino` | ✓ | Two solenoids on MCP23017 (EXP_SOL_1/2), alternating 500 ms | |
| `FED4-TRRS.ino` | ⚠ | TRRS audio jack inputs, front RGB strip group color feedback | Passed with critical fix: pins 2 and 5 need to be swapped; noted in schematic for v1.7.1. |
| `FED4-Temp.ino` | ✓ | BME680 environmental sensor, main I2C bus, temp/humidity/pressure/gas | |
| `FED4-ToF.ino` | ✓ | VL53L1X time-of-flight distance sensor, main I2C bus | |
| `FED4-Touch-Light-Sleep-Multiple.ino` | deferred | Three touch pads, ESP32 light sleep with touchpad wake | Duplicate functionality |
| `FED4-Touch-Pads-beeps.ino` | deferred | Touch pads, I2S speaker beeps, status LED, MCP PSV2/PSV3 | Duplicates core functionality |
| `FED4-Touch.ino` | ✓ | Three ESP32 touch pads, status NeoPixel color feedback | |

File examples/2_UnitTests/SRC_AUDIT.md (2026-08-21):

# FED4 `src/` ↔ Unit-Test Audit

Living checklist for aligning library code with [`examples/2_UnitTests/`](./).  
**Rule:** `src/` never depends on unit-test code; unit tests call library helpers.

## Skip (no accompanying unit test)

| File | Notes |
|---|---|
| `FED4_Menu.cpp` | **Flagged** — rebuild later for new screen; silence/menu UX needs v1.7 retest |
| `FED4.cpp` | Core `run()` / `update()` / `waitUntil()` orchestration |
| `FED4_Buttons.cpp` | **Flagged** — hold→menu / silence / Mario paths need hardware retest + refactor |
| `FED4_Hublink.cpp` | Archive only |
| `FED4_Interrupts.cpp` | Demo mentions INT_OR only |
| `FED4_Score.cpp` | Pong |
| `FED4_Serial.cpp` | Status printf |
| `FED4_Timeout.cpp` | Timeout UI |
| `FED4_Power.cpp` | Power rails (no dedicated UT; SleepModes covers rails) |

## Domain order

1. Touch → 2. Sleep/power → 3. Display → 4. LEDs → 5. Audio → 6. Vitals → 7. Prox/Motion/Motor/Haptic/RTC/SD/Output → Demo integration

## Cross-cutting flags (fix when domain opens)

### P0
- **Version:** `library.properties` was `1.1.0` vs `libraryVer` / board `1.7.0` — **bumped properties to 1.7.0**
- **Ghost `*Pix` APIs** — **Removed**; status LED is `redPix` / `noPix` / `initializePixel` only
- **Phantom `friend class FED4_*`** — **Removed**
- **DISPLAY_WIDTH/HEIGHT** Sharp leftovers (144×168) — **fixed to 320×176** (TN0216)

### P1 contamination
- **Motor `jammed()`** — **soft-fail return** (no longer infinite mini-firmware loop)
- **SD** owns subject/session setters + sequence display state
- **Header comments wrong:** Speaker→Audio, ToF→Prox, solenoids not in Begin
- **Menu / jingles / Mario** — **Flagged** — `menuJingle` / `resetJingle` / `mario*` not Speaker-product audio; refactor when menu returns
- **Button map on v1.7** — **Flagged** — library still owns wake button handling; needs retest after menu rebuild

### P2 unused / ambiguous
- Dead sweep: `logTouchEvent`, `printMemoryStatus`, `majorJamClear`, `onTouchWakeUp`, `sendDisplayCommand`, `fed4TouchReadSmooth`, baseline mirrors — **Removed**
- Naming: `prox` vs `initializeToF` vs file `FED4_Prox.cpp`; `AUDIO_TRRS_*` used for digital TTL
- `displayActivityMonitor()` — kept for later unarchive; no longer switched from `updateDisplay`

## Touch domain (Phase 1) — status

| Item | Status |
|---|---|
| Production still on Arduino `touchRead` / `uint16_t` / 20% abs | **Fixed** — NG `touch_sens` in `FED4_Touch.cpp` |
| Unit-test `FED4_TouchS3` duplicate driver | **Removed** — sketches call library helpers |
| Sleep release-wait still inlined touch math | **Fixed** — uses library rise helpers |
| Feed pellet-well `wakePad` ISR gate | **Fixed** — polls rise / `capturePoke` |
| `interpretTouch` legacy shape | **Done** — `capturePoke()` + FedPad index; shared idle refresh |
| Poke SD rows from sketches | **Done** — `waitUntil` logs `Left`/`Center`/`Right` |

## Sleep / power / sensors — status

| Item | Status |
|---|---|
| Release-wait uses library rise helpers | **Done** |
| Touch wake re-enabled before light sleep | **Done** |
| Dead `handleTouch()` removed | **Done** |
| `FED4-SleepModes` uses library touch helpers | **Done** |
| Power rails peel | **Done** — `FED4_Power.cpp`; Sleep: **PSV2+PSV3 off** in light sleep (quiesce PG/I2S); late retrieval via `waitUntil` only |
| `wakeUp()` sensor contamination | **Done** — sensors via `refreshSensors()` in `update()`; buttons kept in wake by design |
| 10-minute `pollSensors` gate | **Removed** — `refreshSensors()` always reads BME/battery/lux; no auto-`logData("Status")` |
| ActivityMonitor `program ==` branches in hot src | **Removed** — revisit when that sketch is unarchived |
| MIP VCOM keepalive | **Done** — refresh() inverts VCOM then ~30 Hz LEDC KEEP_ALIVE + RC_FAST |
| LEDC vs `analogWrite` conflict | **Fixed** — STATUS_LED is digital only after VCOM LEDC start |
| Wake `Wire.begin()` bare | **Fixed** — `i2cReinitBus()` |
| Accel INT auto-enabled at begin | **Fixed** — INT_OR idle HIGH via H_LACTIVE |
| Sleep budget / early GPIO wakes | **Fixed** — single light-sleep; INT_OR wake off; button-only GPIO wake |
| Event-driven idle API | **Done** — `waitUntil` + `update()` + `FedPad` |
| PIR / `motion()` in idle path | **Deferred** — leave alone until v1.8.0 counter IC |
| STATUS_LED / PIR coupling | **Decoupled** from idle/`update()` |
| Frontlight default | **Off** — `displayLight(false)` in begin |

## Audio domain — status

| Item | Status |
|---|---|
| I2S mono @ 48 kHz vs `FED4-Speaker` | **Aligned** — `initializeSpeaker` / `playTone` match UT |
| Amp SD enable pattern | **Aligned** — HIGH → settle → write → LOW (Speaker UT) |
| Boot `playStartup()` | **Fixed** — ignores `audioSilenced` NVS; Serial notes if silenced; PSV2 settle before init |
| Mario / menu jingles | **Flagged** — legacy; refactor with menu |
| Silence preference (NVS) | Runtime tones honor `audioSilenced`; boot clip does not |

## Begin / Feed / Display (BasicFED4 readiness)

| Item | Status |
|---|---|
| `Wire.setTimeOut(50)` after bus begin | **Done** |
| Probe + recover for MCP/BME/lux/RTC/bat/accel/ToF | **Done** |
| `i2cBusHealthy` stole Wire pins | **Fixed** |
| Low-battery hang | **Fixed** — uses `sleep(sleepSeconds)` |
| `jammed()` infinite loop | **Fixed** — soft-fail + `dispenseError` |
| Program ENV header | **Fixed** — temp + humidity + lux |
| `startVcomLedc` / `stopVcomLedc` | **Done** |
| Full Demo dashboard in library UI | **Out of scope** — stays in `FED4-Demo-Hardware` |

## Hardware verify checklist

Flash with USB CDC On Boot enabled:

1. **FED4-Touch** — NG driver + rising counts on poke
2. **FED4-Touch-Light-Sleep-Multiple** — sleep, wake per pad
3. **FED4-VCOM-LEDC-Light-Sleep** — retest at ~30 Hz (~33 ms period through light sleep)
4. **FED4-Speaker** — Button 1/2 tones (library `playTone` contract)
5. **BasicFED4** — startup sound; left poke → CSV `Left` then feed; VCOM via LEDC in `waitUntil`
6. **FreeFeeding** — replace-when-taken; `update()` refreshes ENV without Status spam

## Programs

- **Unarchived:** [`examples/1_Programs/BasicFED4/`](../1_Programs/BasicFED4/) — `waitUntil()` / `FedPad::Left` / `feed()` / `update()`.
- **Unarchived:** [`examples/1_Programs/FreeFeeding/`](../1_Programs/FreeFeeding/) — `feed()` / `update()`.
- Other sketches remain in `0_Archive/1_Programs/` until their domains are consistent.

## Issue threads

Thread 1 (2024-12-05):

Unable to verify flash chip connection

mattgaidica, 2024-12-05:
```
Connecting....
Chip is ESP32-S3 (revision v0.2)
Features: WiFi, BLE
Crystal is 40MHz
MAC: 34:cd:b0:1a:bf:e8
Uploading stub...
Running stub...
Stub running...
Changing baud rate to 921600
Changed.

A fatal error occurred: Unable to verify flash chip connection (No serial data received.).
```

---

Occurring on MacOS Sonoma 14.6.1, Arduino IDE Version 2.3.4, esp32 Board 3.0.7 (and <3.0). See [ESP32 fails to enter download mode on Macbook via USB C Adapters (ESPTOOL-383) · Issue #712 · espressif/esptool](https://github.com/espressif/esptool/issues/712) for discussion.

Potential fixes:
- Reset capacitor to 10µF
- Add boot button

mattgaidica, 2024-12-06:
10µF cap swap did nothing, I also don't know what resistor the issue above was using.

Setting `Arduino > Tools > Upload Speed > 230400` fixed the upload issue on MacOS.

Closed 2024-12-06.

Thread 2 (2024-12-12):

logData() not working after initial call

KravitzLab, 2024-12-12:
logData() works in the begin function, creating a new file with Event=Startup.
Subsequent calls to logData() in the script cause it to time out and not write to the file.  Added debugging code to the logData() function, confirming that it fails to open the file after the first call.

Also confirmed on the Serial Output that the SD card successfully reinitializes after wakeup:
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

mattgaidica, 2024-12-13:
Do you get any of these print statements at logData? @KravitzLab

void FED4::logData()
{
    greenPix();

    Serial.println ("Getting time");
    DateTime now = rtc.now();

    Serial.print ("Attempting to open file: ");
    Serial.print (filename);
    File dataFile = SD.open(filename, FILE_WRITE);

    if (dataFile)
    {
    Serial.println (" ... opened");
        // DateTime, Event
        dataFile.printf("%04d-%02d-%02d %02d:%02d:%02d,%s,",
                        now.year(), now.month(), now.day(),
                        now.hour(), now.minute(), now.second(),
                        event.c_str());

        // Counters
        dataFile.printf("%d,%d,%d,%d,%d,",
                        pelletCount, leftCount, rightCount, centerCount, wakeCount);

        // Battery and Environmental
        dataFile.printf("%.2f,%.1f,",
                        getBatteryVoltage(),
                        getTemperature());

        // Memory stats
        dataFile.printf("%d,%d,%d\n",
                        ESP.getFreeHeap(),
                        ESP.getHeapSize(),
                        ESP.getMinFreeHeap());

        dataFile.close();
    }

    else {
    Serial.println(" ... Warning: SD file not opened.");
    }
    noPix();
}

mattgaidica, 2024-12-13:
filenames need to be prepended by '/' in ESP32, pushed update

KravitzLab, 2024-12-13:
Reopening this as we're still getting "Warning: SD file not opened."  We've tried the following two approaches but neither works.  I can try more on this over the weekend, it's annoying!

Approach 1:
File dataFile = SD.open(String("/") + filename, FILE_WRITE);

Approach 2:
char fullPath[22];
snprintf(fullPath, sizeof(fullPath), "/%s", filename);
File dataFile = SD.open(fullPath, FILE_WRITE);

Also not sure why this works in the createLogFile function?
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

mattgaidica, 2024-12-24:
Fixed once in software, now fixed in hardware (3.3V tie)

Closed 2024-12-24.

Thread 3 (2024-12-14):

Optimize touch sensing

KravitzLab, 2024-12-14:
Our current method of touch sensing is not 100% reliable at determining which touchpad woke the ESP32.  We need to optimize this.

Touch documentation is here:
https://docs.espressif.com/projects/esp-idf/en/stable/esp32s3/api-reference/peripherals/touch_pad.html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

mattgaidica, 2024-12-14:
I believe I tried touch_pad_get_status() but it tossed a compilation error. I'm less and less impressed with their examples, as they're so bare bones, but this _should_ be ground truth: https://github.com/espressif/arduino-esp32/blob/64b62dc45b008bc578a9918d3b9d537cd07d6ce9/libraries/ESP32/examples/Touch/TouchInterrupt/TouchInterrupt.ino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

We tried that (twice I think!) and it was unreliable.

KravitzLab, 2024-12-14:
It's annoying!  How can waking up on multiple touch pins be such a rare use case?  Here is Espressif declining to provide an example of this functionality in Oct of this year - the fact they won't provide an example makes me worried it can't be done?
https://esp32.com/viewtopic.php?f=5&t=41970&sid=1f24748610ff561d100d7b6717a8efb4

[cid:aeaf556f-38be-4a38-a9bd-e3122eada450]

At some point we might need to add a dedicated touch chip if this is all just too annoying.

The other option is to just re-populate the photogates, we left the footprints for them. They are power hungry but our sleep current would still be in the FED3 range (~10mA) with them on, just seems a shame to burn that much power while sleeping.
-Lex

Alexxai Kravitz, PhD

Department of Psychiatry

Washington University in St Louis

***@***.******@***.***>

________________________________
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

KravitzLab, 2024-12-15:
New example [here](https://github.com/KravitzLabDevices/FED4/blob/main/examples/TouchPadTroubleshooting/WakeOnTouchpad/WakeOnTouchpad.ino) that seems to work better. The important things are:
1) attach T1, T5, and T6 to independent ISRs that keep track of flags for which touchpad was triggered
2) include a 100ms debounce in the ISRs so only one flag can be true at a time

KravitzLab, 2024-12-28:
Example moved [here](https://github.com/KravitzLabDevices/FED4/blob/main/examples/Troubleshooting/TouchPadTroubleshooting/WakeOnTouchpad/WakeOnTouchpad.ino) - try implementing this on FED4

Closed 2025-06-09.

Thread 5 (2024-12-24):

make "event" an argument of logdata()

KravitzLab, 2024-12-24:
Current useage is:
setEvent("PelletDrop");
logData();

Make event an argument for LogData:
logData(event="Pellet");

mattgaidica, 2024-12-24:
Added as optional arg

mattgaidica, 2024-12-24:
CLose

KravitzLab, 2024-12-24:
NeuroTech Hub Premium:
"All issues will be resolved within 15 minutes!"

Closed 2024-12-24.

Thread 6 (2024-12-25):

Create a "setMetaValue" function as a counterpart to "getMetaValue"

KravitzLab, 2024-12-25:
Create a "setMetaValue" function to set JSON values using Arduino script or on-device menus

Desired usage to set "program" from Arduino sketch:
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
with the setMetaValue running behind the scenes to set the program when it is changed.

"program" is the only value that is anticipated to be set from the Arduino sketch, so when users make a custom sketch they can name the sketch and have the custom name propagate to the JSON and logfiles

other values like "id" or "sex" may be set from on-device menus but likely not in Arduino sketch

KravitzLab, 2025-01-13:
Now that you're done with BEAM we thought you might be getting bored.... :)

mattgaidica, 2025-01-13:
One is never done with BEAM. Question is if MetaJson needs to be a library. I'm creating identical functions in Hublink, sooo... long term, yes.

KravitzLab, 2025-01-13:
For now can it be just one more function? :)

Alexxai Kravitz, PhD
Department of Psychiatry
Washington University in St Louis
***@***.******@***.***>

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

Closed 2025-01-14.

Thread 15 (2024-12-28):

Leave front LED strip on during sleep

KravitzLab, 2024-12-28:
This currently requires not shutting down LDO2 for now, not great on power.

This requires a hardware edit but these should be moved to LDO3?  Also write an nonblocking function argument for how long they should stay lit, ie: fed4.leftLight(0xFF0000, 1000); for a red light for 1s.

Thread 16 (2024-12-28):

Use human presence sensor

KravitzLab, 2024-12-28:
Think about how to use this sensor effectively to track homecage mouse activity.

Idea #1: create a dedicated activity sensing mode

Idea #2, poll this sensor every ~1-10s and integrate % active over ~1-10 minute bins, writing a line to the log file for later analysis.

KravitzLab, 2025-07-08:
Using it!  see Motion.cpp

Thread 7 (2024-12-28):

Think about what to use accelerometer for

KravitzLab, 2024-12-28:
This was originally added to wake the device if a user picked it up, thinking the OLED screen which we were using at the time would be off normally, but could be woken when device was picked up.

What can it still be useful for?

Perhaps we can write a short routine to monitor vibration, returning a measure of vibration amplitude and dominant frequency on the rack.

Any other ideas?

mattgaidica, 2024-12-28:
- Put the entire PCB on springs in the housing to measure microvibrations
- Give the user access to specific orientations to act upon, eg, force hublink.sync() when set on one side, go into "shelf mode" when on its back
- Use tap feature (I think it has it?) as user input to menu

KravitzLab, 2024-12-28:
Ahh cool, tap to dispense a pellet would also be useful to test dispensing without removing device from cage!

Get Outlook for Android<https://aka.ms/AAb9ysg>
________________________________
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

KravitzLab, 2025-01-05:
If accelerometer can't wake the device this limits uses somewhat....  we could:
1. Measure vibration in an "environmental monitoring mode" where FED4 wakes every 10minutes or something to monitor and log the in cage environment.
2. Is there any value in reading accelerometer during trials?  Like after mouse wakes it up with a poke?  Magnetometer would be useful here, is accelerometer?
3. For the most superfluous FED4 function we could auto-rotate the screen :)

KravitzLab, 2025-01-14:
Honestly I can't think of much that's useful for this without waking the device.  Closing this for now...

Closed 2025-01-14.

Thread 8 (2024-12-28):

Make pollSensors function

KravitzLab, 2024-12-28:
The temperature sensor can sometimes take a few hundred ms to time out so we don't want to call it every time we update the display or log data.

Make a pollSensors() function that uses millis() to only poll temp/humidity/battery every 10 minutes, and only do it after a pellet delivery when a delay is not as critical.

KravitzLab, 2024-12-28:
Completed, but need to update this function to add light level reading from ToF.

KravitzLab, 2024-12-30:
Completed this, and call is after feed() and only every 10 minutes.

Closed 2024-12-30.

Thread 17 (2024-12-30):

Log motorTurns and stop turning if jammed

KravitzLab, 2024-12-30:
Logging the motorTurns value can give insight to jams when they happen.  Also if the motorTurns breaks a threshold (>200?) it's probably jammed and we should stop attempting to dispense because it's just spinning.

Here is battery life after 3 days, red arrow shows when pellets ran out and motor burned itself out
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

KravitzLab, 2024-12-30:
Logging motorTurns as "DispenseTurns", which logs how many 1/8 turns the hopper makes:
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

Also implemented a jammed() function to activate after N failed dispense attempts, displaying "DISPENSE ERR" on the screen and going to sleep.

```
void FED4::jammed(){

  fillRect (0, 0, 144, 17, DISPLAY_BLACK);

  setFont(&Org_01);
  setTextSize(2);
  setTextColor(DISPLAY_WHITE);

  setCursor(0, 9);
  print("DISPENSE ERR");
  refresh();
  releaseMotor();

  while(1) {
    // Infinite loop to hang the program
    LDO2_OFF();
    enableAmp(false);
    // put FED4 to sleep
    esp_light_sleep_start();
    delay(1000);
  }
}
```

Closed 2024-12-30.

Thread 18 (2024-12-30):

Create unique deviceName variable and log it

KravitzLab, 2024-12-30:
need a unique device ID in the logfile

KravitzLab, 2024-12-30:
Using mouseID from meta.json, logging along with libraryVer and program:
```

 // Write all data
    dataFile.printf("%04d-%02d-%02d %02d:%02d:%02d,%f,%s,%s,%s,%s,",
                    now.year(), now.month(), now.day(),
                    now.hour(), now.minute(), now.second(),
                    currentSeconds,
                    libraryVer.c_str(), mouseId.c_str(), program.cstr(), event.c_str());
```

Closed 2024-12-30.

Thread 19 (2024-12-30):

If temperature reading is 0, don't update it

KravitzLab, 2024-12-30:
Sometimes the temperature sensor does not return a real value, resulting in 0.  In this case, don't update it and just use last reading:
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

KravitzLab, 2024-12-30:
Added constraints to get temporary readings and only update "temperature" and "humidity" variables if the returned values are >5
```

    float temp = getTemperature();
    float hum = getHumidity();

    if (temp > 5){  //only update temp if it's a good reading
    temperature = getTemperature();
        }
    if (hum > 5){  //only update humidity if it's a good reading
        humidity = getHumidity();
    }
```

Closed 2024-12-30.

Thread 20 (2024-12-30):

Differentiate pokes that dispense pellets vs. not

KravitzLab, 2024-12-30:
For FED3 we used:
"Left"
"LeftWithPellet"
"LeftDuringDispense"

to differentiate these

KravitzLab, 2024-12-30:
this will require modifying the feed() function to log pokes with pellet in the well, etc

KravitzLab, 2025-01-03:
Added condition to feed() function to log pokes while pellet is present in well:

```
while (pelletPresent)
    { // while pellet is in well
        bluePix();
        pelletPresent = checkForPellet();
        retrievalTime = (millis() - pelletWellTime) / 1000.0;
        if (retrievalTime > 10)
            break;

        //log pokes while pellet is in well
        // Read current touch values
        uint16_t leftVal = touchRead(TOUCH_PAD_LEFT);
        uint16_t centerVal = touchRead(TOUCH_PAD_CENTER);
        uint16_t rightVal = touchRead(TOUCH_PAD_RIGHT);

        // Check for significant deviations from baseline
        float leftDev = abs((float)leftVal / touchPadLeftBaseline - 1.0);
        float centerDev = abs((float)centerVal / touchPadCenterBaseline - 1.0);
        float rightDev = abs((float)rightVal / touchPadRightBaseline - 1.0);

        Serial.printf("Touch values - Left: %d/%d, Center: %d/%d, Right: %d/%d\n",
                  leftVal, touchPadLeftBaseline,
                  centerVal, touchPadCenterBaseline,
                  rightVal, touchPadRightBaseline);

        Serial.printf("Deviations - Left: %f, Center: %f, Right: %f\n",
                  leftDev, centerDev, rightDev);

        // Only log if there's a significant deviation
        if (leftDev >= TOUCH_THRESHOLD) {
            leftCount++;
            logData("LeftWithPellet");
            greenPix();
            outputPulse(AUDIO_TRRS_1, 100);
        }
        else if (centerDev >= TOUCH_THRESHOLD) {
            centerCount++;
            logData("CenterWithPellet");
            bluePix();
            outputPulse(AUDIO_TRRS_2, 100);
        }
        else if (rightDev >= TOUCH_THRESHOLD) {
            rightCount++;
            logData("RightWithPellet");
            redPix();
            outputPulse(AUDIO_TRRS_3, 100);
        }
    }

```

Closed 2025-01-03.

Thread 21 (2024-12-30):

Fix the dates on windows of files on SD cards

ChantelleMurrell, 2024-12-30:
Change these dates modified to the actual dates of the fed4 files

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

KravitzLab, 2025-01-05:
Followed guidance [here](https://forum.arduino.cc/t/esp32-how-to-add-timestamp-on-sd-files-withou-ntp/943194/19) to use [ESP32Time library](https://github.com/fbiego/ESP32Time) by Felix Biego  to set the internal RTC time on the ESP32 with the time from the external DS3231 RTC. The internal RTC time is then used to set the correct DateModified timestamp when data file is created. I'm shocked this worked!

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

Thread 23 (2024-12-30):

read lux from ToF

KravitzLab, 2024-12-30:
variable "lux" is being written to SD card, but not updating correctly from ToF sensors

KravitzLab, 2024-12-31:
It seems that the Lux values are being written correctly, but not being returned correctly from the ToFs.  These sensors all report 0.00 for Lux at gain of 5.  If we push gain to 40 (highest in library) they sit at ~0.01 and shining a flashlight on it makes it sometimes hit 0.08 but it's not reliable (and should be returning values 1000x higher).

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

KravitzLab, 2024-12-31:
Some life:
The increase below (at x=~120) is me pointing the FED out the window for a couple seconds, this increases the reading.  But it's not accurate, too low.
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

KravitzLab, 2024-12-31:
Turns out [VL6180 is EOL](https://community.st.com/t5/imaging-sensors/vl6180-eol-vl53-as-subtitute/td-p/668715)!  This is an issue that we don't need to nail down if we switch off VL6180...

Closed 2024-12-31.

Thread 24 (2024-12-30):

Hold top button for 3s to reset device

KravitzLab, 2024-12-30:
That would be easier than flicking on/off switch or pushing inside reset button

KravitzLab, 2024-12-30:
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

KravitzLab, 2025-01-18:
Complete.  Button 1 for 1s forces a feed, Button 2 for 3s forces a reset

Closed 2025-01-18.

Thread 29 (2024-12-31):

audio doesn't always sound great

KravitzLab, 2024-12-31:
stimuli sometimes sound crunchy, othertimes great.
maybe it needs more time to bring amp up to power after sleep?

KravitzLab, 2025-01-02:
Reduced sample_rate, dma_buf_count, and dma_buf_len in initializeSpeaker to reduce buffer size and associated latency.
Tones sounds good now with delay (1) in enableAmp()!

```
bool FED4::initializeSpeaker()
{
    // I2S configuration for MAX98357A
    i2s_config_t i2sConfig = {
        // other settings not changed
        .sample_rate = 22050,   // Reduced from 44100 to 22050 to reduce latency
        .dma_buf_count = 2,     // Reduced from 8 to improve responsiveness
        .dma_buf_len = 256,     // Reduced from 1024 to improve responsiveness
        .use_apll = true,       // Changed to true for better clock accuracy

    };
```

Also reduced default amplitude from 0.5 to 0.25 which lowers volume and makes audio sound better.

And added amplitude argument to playTone to allow user to control volume of tones
`void FED4::playTone(uint32_t frequency, uint32_t duration_ms, float amplitude)`

Closed 2025-01-02.

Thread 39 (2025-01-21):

AdjustRTC at Compile Time Requires Clearing Cache

mattgaidica, 2025-01-21:
Cached compilations can result in stale __DATE__ and __TIME__ ∴ requires pressing shift + upload in Arduino IDE. @KravitzLab

The routine won't update the RTC if it has been previously set and recognizes a cached compile time (it stores a compilation datetime string in non-volatile memory using "preferences"). Still, if there is a more recent (including a cached) compilation, the RTC could reflect the cached compilation datetime. Options:

1. The flasher needs to remember to use shift + upload.
2. RTC setting uses a different script, but flasher STILL needs to shift + upload. This is kind of dumb and painful (To flash twice) but it might reduce the possibility of error. You would need to disable adjustRTC() in begin.
3. Fancier stuff: Hublink RTC, standalone python script to connect to port and serialize datetime, etc.

KravitzLab, 2025-01-21:
We do the annoying #2 option with FED3 :)

The other option (which we also do with FED3) is to put a time-setting mode on the device itself - that can be a convenient back stop for any clock adjustments.  I'll open an issue for that and knock it out at some point.

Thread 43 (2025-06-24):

Use SMD haptic motor

KravitzLab, 2025-06-24:
Something like this: https://www.precisionmicrodrives.com/surface-mount-smd-smt-vibration-pager-motors

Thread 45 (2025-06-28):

Use ToF to do Mason's Pavlovian task

KravitzLab, 2025-06-28:
Write script where tone goes off, then FED4 drops pellet.  Over time, adjust:
1) tone only goes off if Prox reading is 100-150,
2) increment waiting period duration which mouse has to stay in that Prox range to 5s
3) only dispense pellet if mouse moves closer so Prox <50 within 3s

KravitzLab, 2025-07-08:
Prox sensor implemented, call fed4.prox() from the Arduino sketch to return the prox reading

Closed 2025-07-08.

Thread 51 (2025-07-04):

implement hot swapping SD cards

KravitzLab, 2025-07-04:
If the card is popped in and out, continue writing on current file.  This will require re-init'ing the SD card periodically, this could be done at the status report, instead of at every logdata call like FED3 does

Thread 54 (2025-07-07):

make  light sensor log 1/hour

KravitzLab, 2025-07-07:
To get maximum sensitivity we do an 800ms integration time on the light sensor.  Let's only do this one time per hour to not hang the device.

Could think about doing all environmental sensing after a feed too

KravitzLab, 2025-07-07:
Is light sensor blocking?  Could we poll it during dispense?

Closed 2025-07-08.

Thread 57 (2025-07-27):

Add silent function for debugging

KravitzLab, 2025-07-27:
Call fed4.silent() in setup to silence the speaker.  (Also could be a user key shortcut?)

KravitzLab, 2025-07-27:
Added silence() and unsilence() functions.  Visual indicator "X" icon at top of the screen next to Temp to indicate when audio is disabled.

Control audio silencing with Button 3:
1.	Audio toggle: Hold button 3 for 0.5 seconds to toggle audio on/off
        (Or call fed4.silence() in code but this is unlikely to be used this way.)
2.	Menu access: Hold button 3 for 1.5 seconds to enter the menu to edit meta.json items

Closed 2025-07-27.

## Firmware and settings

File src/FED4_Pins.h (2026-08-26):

#ifndef FED4_PINS_h
#define FED4_PINS_h

// Motor Control Pins
#define MOTOR_PIN_1 38 // A2 motor
#define MOTOR_PIN_2 45 // A3 motor
#define MOTOR_PIN_3 46 // A4 motor
#define MOTOR_PIN_4 47 // A5 motor

// User Buttons
#define BUTTON_1 15 // User Button 1 - bottom
#define BUTTON_2 16 // User Button 2 - middle
#define BUTTON_3 39 // User Button 3 - top

// Touch Sensor Pins (ESP32-S3: GPIO number == touch channel index for pads 1–14)
// Face-on poke ports (verified FED4-Touch): Left=GPIO1, Center=GPIO3, Right=GPIO2
#define TOUCH_PAD_LEFT 1   // GPIO1 / touch channel 1
#define TOUCH_PAD_CENTER 3 // GPIO3 / touch channel 3
#define TOUCH_PAD_RIGHT 2  // GPIO2 / touch channel 2

// Photogate Pins
#define PHOTOGATE_1 14 // Center
#define PHOTOGATE_2 17 // Left
#define PHOTOGATE_3 18 // Right
#define PHOTOGATE_4 37 // Pellet Detector

// PIR Motion Sensor
#define PIR_MOTION 10 // PIR motion sensor

// Audio/GPIO Interface
#define AUDIO_TRRS_1 4 // Audio TRRS pin 1
#define AUDIO_TRRS_2 5 // Audio TRRS pin 2
#define AUDIO_TRRS_3 6 // Audio TRRS pin 3

// Interrupt Logic
#define INT_OR 7 // Interrupt ORing logic

// Amplifier Interface
#define AMP_LRCLK 40 // Amplifier left right clock
#define AMP_BCLK 41  // Amplifier bit clock
#define AMP_DIN 42   // Amplifier data input
#define EXP_AMP_SD 4 // Amplifier SD line on GPIO expander

// SPI Interface
#define SPI_MOSI 13 // SPI master output, slave input
#define SPI_SCK 12  // SPI clock
#define SPI_MISO 11 // SPI master input, slave output
#define SD_CS 48    // SD card chip select

// Display Interface
#define DISPLAY_CS 44       // Display chip select
#define DISPLAY_VCOM 43     // Display VCOM
#define EXP_DISPLAY_RESET 6 // Display reset on GPIO expander
#define EXP_DISPLAY_LED 7   // Display LED on GPIO expander

// I2C Interface
#define SDA 8 // I2C data
#define SCL 9 // I2C clock

// I2C Device Addresses
#define I2C_ADDR_ACCEL 0x19    // LIS2DH12TR  (SA0=HIGH)
#define I2C_ADDR_BME680 0x76   // BME680       (SDO=LOW)
#define I2C_ADDR_MCP23017 0x20 // MCP23017     (A0/A1/A2=LOW)
#define I2C_ADDR_MAX17048 0x36 // MAX17048     (fixed)
#define I2C_ADDR_RTC 0x68      // DS3231       (fixed)
#define I2C_ADDR_TOF 0x29      // VL53L1X      (fixed)
#define I2C_ADDR_LIGHT 0x10    // VEML7700     (fixed)

// Power Management (TPS22917 load switch ~ON — active LOW: LOW = rail ON, HIGH = rail OFF)
#define EXP_PSV2_EN 13 // PSV2 enable on GPIO expander (MCP pin 13)
#define EXP_PSV3_EN 12 // PSV3 enable on GPIO expander (MCP pin 12)

// User Control Pins
#define USER_SRV_INT 21  // User Servo or interrupt
#define EXP_USER_GPX0 8  // User pin 8 on GPIO expander
#define EXP_USER_GPX1 9  // User pin 9 on GPIO expander
#define EXP_USER_GPX2 10 // Touch point 10 on GPIO expander
#define EXP_USER_GPX3 11 // Touch point 11 on GPIO expander

// Solenoid Control
#define EXP_SOL_1 2 // Solenoid 1 on GPIO expander
#define EXP_SOL_2 3 // Solenoid 2 on GPIO expander

// LED Control
#define STATUS_LED 35 // Status LED
#define RGB_STRIP 36  // front LEDs

// Haptic Motor
#define EXP_HAPTIC 5 // Turns on/off haptic motor

#endif

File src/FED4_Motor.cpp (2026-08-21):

#include "FED4.h"
// NOTE: YOU NEED A BATTERY PLUGGED IN FOR THE MOTOR TO RUN.

bool FED4::initializeMotor()
{
    pinMode(MOTOR_PIN_1, OUTPUT);
    pinMode(MOTOR_PIN_2, OUTPUT);
    pinMode(MOTOR_PIN_3, OUTPUT);
    pinMode(MOTOR_PIN_4, OUTPUT);
    stepper.setSpeed(MOTOR_SPEED);
    return true;
}

void FED4::releaseMotor()
{
    digitalWrite(MOTOR_PIN_1, LOW);
    digitalWrite(MOTOR_PIN_2, LOW);
    digitalWrite(MOTOR_PIN_3, LOW);
    digitalWrite(MOTOR_PIN_4, LOW);
}

void FED4::minorJamClear()
{
    Serial.println("MinorJam");
    stepper.step(200);
    delay(1000);
}

void FED4::vibrateJamClear()
{ // make this function also monitor the pellet well
    Serial.println("VibrateJam");
    for (int i = 0; i < 35; i++)
    {
        stepper.step(10);
        delay(10);
        stepper.step(-20);
        delay(10);
    }
}

void FED4::jammed()
{
  fillRect(0, 0, 176, 17, DISPLAY_BLACK);

  setFont(&Org_01);
  setTextSize(2);
  setTextColor(DISPLAY_WHITE);

  setCursor(0, 9);
  print("DISPENSE ERR");
  refresh();
  releaseMotor();
  logData("DispenseError"); // reclaimSpiForDisplay inside; UI already refreshed above
  lightsOff();
  noPix();

  // Soft-fail: let feed() finish and the program loop continue
  dispenseError = true;
  pelletReady = false;
  motorTurns = 0;
  Serial.println("Jam: soft-fail — returning to program loop");
}

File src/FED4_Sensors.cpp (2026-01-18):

#include "FED4.h"

// Initialize the static member
uint8_t FED4::wakePad = 0;  // 0=none, 1=left, 2=center, 3=right

// Separate ISR callbacks for each touch pad (avoids legacy driver API calls)
void IRAM_ATTR FED4::onTouchWakeUp()
{
    // Generic wake-up handler - wakePad is set by specific handlers below
}

// ISR callbacks for touch pad interrupts - names match the physical pad they're attached to
void IRAM_ATTR onLeftPadTouch() {
    FED4::wakePad = 1;  // LEFT pad
}

void IRAM_ATTR onCenterPadTouch() {
    FED4::wakePad = 2;  // CENTER pad
}

void IRAM_ATTR onRightPadTouch() {
    FED4::wakePad = 3;  // RIGHT pad
}

bool FED4::initializeTouch()
{
    // Use Arduino's touch API which handles all low-level initialization
    // The first touchRead() call will initialize the touch subsystem automatically
    // Just verify that the touch pads are responsive by doing a test read
    uint16_t testLeft = touchRead(TOUCH_PAD_LEFT);
    uint16_t testCenter = touchRead(TOUCH_PAD_CENTER);
    uint16_t testRight = touchRead(TOUCH_PAD_RIGHT);
    
    // Verify we got valid readings (non-zero values)
    if (testLeft == 0 || testCenter == 0 || testRight == 0) {
        return false;
    }
    
    delay(25);  // Allow touch subsystem to stabilize
    return true;
}

void FED4::calibrateTouchSensors()
{
    // Detach existing interrupts to prevent memory leaks
    touchDetachInterrupt(TOUCH_PAD_LEFT);
    touchDetachInterrupt(TOUCH_PAD_CENTER);
    touchDetachInterrupt(TOUCH_PAD_RIGHT);
    
    // Small delay to ensure interrupts are fully detached before reattaching
    delay(10);

    touchPadLeftBaseline = touchRead(TOUCH_PAD_LEFT);
    touchPadCenterBaseline = touchRead(TOUCH_PAD_CENTER);
    touchPadRightBaseline = touchRead(TOUCH_PAD_RIGHT);

    uint16_t left_threshold = touchPadLeftBaseline * TOUCH_THRESHOLD;
    uint16_t center_threshold = touchPadCenterBaseline * TOUCH_THRESHOLD;
    uint16_t right_threshold = touchPadRightBaseline * TOUCH_THRESHOLD;

    // Serial.printf("Touch sensor thresholds - Left: %d, Center: %d, Right: %d\n",
    //               left_threshold, center_threshold, right_threshold);

    // Enable wake-up on touch pads
    esp_sleep_enable_touchpad_wakeup();

    // Attach interrupt callbacks - each callback is now correctly named for its physical pad
    touchAttachInterrupt(TOUCH_PAD_LEFT, onLeftPadTouch, left_threshold);
    touchAttachInterrupt(TOUCH_PAD_CENTER, onCenterPadTouch, center_threshold);
    touchAttachInterrupt(TOUCH_PAD_RIGHT, onRightPadTouch, right_threshold);
}

/**
 * Interprets which touch sensor was activated after waking from sleep
 * Sets the appropriate touch flag (leftTouch, centerTouch, rightTouch) 
 * Increments the corresponding counter
 * 
 * Note: Physical pad to touch mapping is rotated:
 * - LEFT pad (wakePad=1) → centerTouch
 * - CENTER pad (wakePad=2) → rightTouch
 * - RIGHT pad (wakePad=3) → leftTouch
 * 
 * The hardware interrupt has already verified the touch is above threshold,
 * so we trust the wakePad value without re-checking (which could fail if
 * the touch value has decayed by interpretation time).
 */
void FED4::interpretTouch()
{
    // Map wakePad values to touch flags (compensating for rotated mapping)
    // Hardware interrupt already validated threshold, so we trust wakePad value
    if (wakePad == 1) {  // LEFT pad → triggers centerTouch
        centerCount++;
        centerTouch = true;
    } else if (wakePad == 2) {  // CENTER pad → triggers rightTouch
        rightCount++;
        rightTouch = true;
    } else if (wakePad == 3) {  // RIGHT pad → triggers leftTouch
        leftCount++;
        leftTouch = true;
    }
    wakePad = 0;  // Reset the wake pad flag
}

void FED4::resetTouchFlags()
{
    leftTouch = false;
    centerTouch = false;
    rightTouch = false;
}

// Optional: Add this function to log touch events separately from the critical path
void FED4::logTouchEvent()
{
    if (leftTouch) {
        Serial.print("LEFT touch   ");
    } else if (centerTouch) {
        Serial.print("CENTER touch ");
    } else if (rightTouch) {
        Serial.print("RIGHT touch  ");
    }
}

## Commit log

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2024-12-10 fixed SD card issues, logData("Startup") works!
    [FED4.h, FED4_SD.cpp]
2024-12-10 memory leak fixed (display.begin should only be called once); reducing touch interrupt overhead; event setter/getter
    [FED4.cpp, FED4.h, FED4_Display.cpp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]
2024-12-11 Updating Feed function to include jam clearing
    [FED4.cpp, FED4.h]
2024-12-11 Added jam clear movements, initializeMotor() at begin
    [BasicFED4.ino, FED4.cpp, FED4.h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]
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2024-12-12 speaker skeleton, not working yet and pushes byes to the Serial terminal?
    [FED4.cpp, FED4.h, FED4_Speaker.cpp]
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2024-12-16 LDO2 not allowing re-init of SD; added public left/center/rightTouch bools, reset in feed()
    [FED4.cpp, FED4.h, FED4_SD.cpp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]
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2024-12-18 Noticing issue with screen turning on at boot sometimes, added delay in begin()
    [FED4.cpp, FED4_SD.cpp]
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2024-12-20 yikes prior commit had some issues, this one is stable
    [FED4.cpp, FED4.h, FED4_Display.cpp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]
2024-12-20 Fixed accel init, rm isBatteryConnected (wasn't useful)
    [FED4.cpp, FED4.h, FED4_Accel.cpp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]
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2024-12-25 fixed battery icon
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2024-12-29 Closes #11 , however, RTC Lib doesn't have native support for DateTime milliseconds, we would have to handle it manually to include in the DateTime column... I would rather have the user decide how t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
    [FED4_SD.cpp]
2024-12-30 Updated logging file format and motor handling
    Logging updates
    - Now logging humidity
    - Stopped temperature from logging at 0 with bad reading
    - Logging lux (not finished)
    - Logging motorTurns (pelletTurns)
    - Added logging calls in poke and feed functions
    - Rearranged log file columns
    Motor updates
    - Released motor between movements to reduce power
    - Added a "jammed" mode after N failed dispensing attempts that shuts FED4 down and displays "DISPENSE ERR" on screen.
    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
    [FED4.cpp, FED4.h, FED4_Motor.cpp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]
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2025-01-02 Fixed bug in pollSensors that could hang FED4
    [FED4.cpp, FED4.h, FED4_Speaker.cpp]
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2025-01-05 Fixed DateModified for SD files
    [FED4.h, FED4_RTC.cpp]
2025-01-13 Fixed Retrieval Time logging
    [FED4.cpp, FED4_SD.cpp]
2025-01-14 Update FED4_Display.cpp
    Fix time display
    [FED4_Display.cpp]
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2025-01-18 Added function to hold btn2 to force reset
    [FED4.h, FED4_Buttons.cpp, FED4_Speaker.cpp]
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2025-03-05 Revert "updates"
    This reverts commit aaece5324ff4fe33f1bb2a29ee1baa4a8312a96b.
    [FED4.cpp, FED4.h, FED4_Pins.h]
2025-03-05 Revert "v1.5"
    This reverts commit 0c64b0163016898dfe610e2c8b4b9988b2c6d9cd.
    [FED4.h, FED4_Begin.cpp, FED4_Motor.cpp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]
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2025-06-06 fixed click sound by adding small delay
    [FED4.cpp, FED4.h, FED4_Feed.cpp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]
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2025-06-08 fixed audio at startup
    [FED4_Begin.cpp, FED4_SD.cpp, FED4_Speaker.cpp]
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2025-06-09 simplified resetting touch flags
    [FED4.h, FED4_Begin.cpp, FED4_Feed.cpp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]
2025-06-11 initiatlize haptic pin correctly
    [FED4_Begin.cpp]
2025-06-24 fixed light sensor memory leak
    [FED4.h, FED4_Begin.cpp, FED4_Vitals.cpp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]
2025-06-24 updated memory leak stuff
    [FED4.h, FED4_SD.cpp, FED4_Vitals.cpp]
2025-06-25 fixed lioght sensor
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2025-06-30 fixed SD card thing
    [FED4_Motion.cpp, FED4_SD.cpp, FED4_Sleep.cpp]
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2025-07-02 handle sd card errors while allowing device to continue running
    [FED4.h, FED4_Begin.cpp, FED4_Display.cpp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]
2025-07-08 fixed motion, other updates
    [FED4.h, FED4_Motion.cpp, FED4_Motor.cpp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]
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2025-07-27 save silence audio state across resets
    [FED4_Audio.cpp]
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2025-09-08 Update sequence learning logic and display feedback
    Increase pellets required per level and start level in SequenceLearning.ino. Reset block pellet and poke counters on level increase in SequenceLearning_Helpers.h. Improve display to show the entire required sequence for the current level in FED4_Display.cpp. Increment block pellet count when a pellet is dispensed in FED4_Feed.cpp.
    [FED4_Display.cpp, FED4_Feed.cpp, SequenceLearning.ino]
2025-09-08 Turn off LEDs after sequence completion
    Added a call to fed4.lightsOff() after a correct sequence is completed to ensure LEDs are turned off before feeding. Also updated the comment for lightsOff() to clarify its effect.
    [FED4_LEDs.cpp]
2025-09-10 Enhance SequenceLearning with button level advance
    Added functionality to advance the sequence level using BUTTON_1 in SequenceLearning.ino, with audio feedback and logging. Modified SequenceManager to support forced level advancement and updated error/timeout handling to only reset counters when the level increments. Added new laser cutting and image files, and made minor formatting and comment improvements.
    [FED4_laserfrontNoLogo091025.dxf]
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2025-09-14 Add light cueing system for sequence learning task
    Implemented a yellow light cue to indicate the next required poke in the sequence. The cue updates after each correct poke and resets to the first poke on error. Refactored code to remove redundant colored feedback and ensure cueing is consistent throughout the task.
    [SequenceLearning.ino]
2025-09-14 Adjust light control and add delay in sequence helper
    Removed redundant lightsOff() call after sequence completion and added a short delay after setting LED state to ensure proper operation.
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2025-09-16 Improve SD card initialization and hot swap handling
    Refactored SD card initialization to remove redundant retries and streamline the process. Enhanced logData to attempt SD card reinitialization and file reopening if the log file cannot be opened, supporting SD card hot swapping and improving robustness against SD card errors.
    [FED4_SD.cpp]
2025-09-16 Add timeout to SD.open() for improved reliability
    Introduces a timeout loop when opening files on the SD card to handle cases where the card may not be immediately ready, both during initial open and after reinitialization. This change aims to improve robustness, especially when hot swapping SD cards.
    [FED4_SD.cpp]
2025-09-25 Adjust motion sensor threshold and hysteresis values
    Lowered the motion threshold from 40 to 30 and increased the hysteresis from 8 to 10 in FED4_Motion.cpp. Updated FED4_Vitals.cpp to set the motion threshold to 30 for consistency. These changes aim to improve motion detection sensitivity and stability.
    [FED4_Motion.cpp, FED4_Vitals.cpp]
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2025-10-27 Refactor activity tracking to use FED4 counters
    Replaces local activity tracking variables with FED4's internal motionCount and pollCount for consistency. Updates display and logging to calculate activity percentage in real-time, and adjusts display labels for clarity.
    [ActivityMonitor.ino, FED4_Display.cpp, FED4_SD.cpp]
2025-10-29 Refine activity logging and display calculations
    Improves the ActivityMonitor example by clarifying polling and logging intervals, simplifying the loop, and enhancing LED and serial output logic. Updates display and SD logging to use rounded and precomputed motion percentage values, and removes unnecessary resets of motionPercentage in sensor polling.
    [ActivityMonitor.ino, FED4_Display.cpp, FED4_SD.cpp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]
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2025-11-12 Refactor motion sensor initialization and display text
    Updated display labels for brevity and adjusted cursor positions in FED4_Display.cpp. Refactored motion sensor initialization in FED4_Vitals.cpp to use initializeMotion(), and updated motion threshold and hysteresis values in FED4_Motion.cpp for improved stability and sensitivity. Removed redundant delay and clarified I2C bus initialization for distance sensor.
    [FED4_Display.cpp, FED4_Motion.cpp, FED4_Vitals.cpp]
2025-11-13 Adjust motion sensor settings and improve I2C init
    Reduced motion sensor power-up delay and increased hysteresis for stability. Updated comments and replaced distance sensor initialization with prox() call to exercise I2C bus on ESP32-S3. Set motionDetected flag for immediate detection and removed unnecessary display clearing.
    [FED4_Motion.cpp, FED4_Vitals.cpp]
2025-11-13 Improve ActivityMonitor sleep and pong game visuals
    Set sleep interval to 6 seconds in ActivityMonitor example for better battery life. Refactor pong game to use animated mouse graphics for paddles, improve collision logic, and optimize score display updates. Add display update call in sensor polling for more responsive UI.
    [ActivityMonitor.ino, FED4_Begin.cpp, FED4_Score.cpp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]
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2025-11-18 Refactor motion sensor to use Adafruit_STHS34PF80
    Replaces SparkFun_STHS34PF80 library usage with Adafruit_STHS34PF80 for motion sensor. Updates initialization, configuration, and motion detection logic to match Adafruit API. Adds I2C_2 fast mode and improves sensor reinitialization after wake-up.
    [FED4.h, FED4_Begin.cpp, FED4_Motion.cpp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]
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2025-12-03 Improve motion tracking and SD logging reliability
    Refactored motion detection to use real-time percentage calculation and added a method to reset motion counters after logging. Enhanced SD card logging with additional error checks and warnings for file creation and write failures. Updated ActivityMonitor example to use faster sampling and logging intervals, removed redundant serial output, and improved timer initialization. Adjusted sleep/wake logic to avoid unnecessary sensor reinitialization and prevent LDO2 shutdown for ActivityMonitor. Minor code cleanups and improved comments for clarity.
    [ActivityMonitor.ino, FED4.h, FED4_Begin.cpp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]
2025-12-03 Fix TRRS naming and guard motion percentage division
    Corrects 'TRSS' to 'TRRS' in function names and comments for audio connector handling. Adds division by zero guard when calculating motion percentage in FED4_Motion.cpp to prevent runtime errors.
    [FED4.h, FED4_Motion.cpp, FED4_Output.cpp]
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2025-12-15 Comment out LDO2 shutdown in sleep for ActivityMonitor
    Disabled the LDO2 shutdown and its debug print in FED4::startSleep() for all programs except ActivityMonitor, as ActivityMonitor does not function correctly when LDO2 is turned off. No functional changes to ActivityMonitor. Minor whitespace cleanup in ActivityMonitor.ino.
    [ActivityMonitor.ino, FED4_Sleep.cpp]
2025-12-30 Improve jammed state handling and add dispense logging
    Enhanced the jammed() function to turn off LEDs, enter light sleep with periodic sensor polling, and reinitialize I2C buses on wakeup. Added serial output during dispensing to log pellet positions. Updated interpretTouch() comment to reflect removal of logging and display updates.
    [FED4_Feed.cpp, FED4_Motor.cpp, FED4_Sensors.cpp]
2026-01-03 Update 3D and laser cutting files for FED4 design
    Added new FED4 3D design STL files and removed outdated Apr2025 versions. Renamed laser cutting files to use consistent lowercase directory naming.
    [FED4_010126_Base.stl, FED4_010126_Hopper.stl, FED4_010126_Housing.stl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]
2026-01-03 Update laser cutting and 3D design files for FED4_010126
    Added new STL and updated DXF/SVG files for FED4_010126 front, hopper lid, nose, and side door. Removed outdated laser cutting files to reflect the latest design revisions.
    [FED4_010126_Front.dxf, FED4_010126_Front.stl, FED4_010126_HopperLid.dxf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]
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2026-01-15 Add advanced haptic feedback patterns and fix touch callback mapping
    Introduced new haptic feedback methods (sine wave, ramp, throb) in FED4_Haptic.cpp and updated default durations for buzz patterns. Moved haptic methods from FED4_Motor.cpp to a dedicated file. In FED4_Sensors.cpp, added a delay after detaching touch interrupts and adjusted callback-to-pad mapping to address ESP32-S3 callback rotation issue.
    [FED4.h, FED4_Motor.cpp, FED4_Sensors.cpp]
2026-01-15 Refactor haptic feedback patterns and update API
    Replaces hapticSineWave and hapticRamp with hapticRampUp and hapticRampDown using cubic curves for smoother feedback. Updates hapticThrob to use a fast-rise, slow-end curve and adjusts default durations for more pronounced effects. Also changes a debug message in motion initialization to use Serial.println for consistency.
    [FED4.h, FED4_Motion.cpp]
2026-01-15 Replace haptic ramp/throb effects with rumble
    Removed hapticRampUp, hapticRampDown, and hapticThrob methods and replaced them with a new hapticRumble method for a low-frequency rumble effect. Updated header and implementation to simplify haptic feedback options.
    [FED4.h]
2026-01-15 Update default hapticRumble duration to 100ms
    Changed the default duration for hapticRumble from 500ms to 100ms in FED4.h to provide a shorter rumble effect. No functional changes in FED4_Haptic.cpp.
    [FED4.h]
2026-01-16 Improve motion sensor disabled handling and haptic tuning
    Updates haptic feedback defaults and timing for triple buzz and rumble. Refines handling of disabled motion sensor: sets motionPercentage to NAN, outputs 'Disabled' in SD logs, and updates serial status report to indicate when motion sensor is disabled.
    [FED4.h, FED4_Motion.cpp, FED4_SD.cpp]
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2026-01-17 fixed audio issues with new I2S library
    [FED4_Audio.cpp, FED4_Begin.cpp, FED4_Display.cpp]
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2026-01-17 Refactor I2C handling and improve status display labels
    Standardizes I2C bus speeds to 100kHz for reliability, removes dynamic I2C speed changes, and updates initialization status labels for clarity (e.g., 'GPIO expander', 'Power management', 'Audio output'). Improves display buffer clearing in startup animation to prevent flickering and adds log filename display (with truncation for long names) during log file creation.
    [FED4_Begin.cpp, FED4_Display.cpp, FED4_SD.cpp]
2026-01-18 Fix and clarify touch pad interrupt mapping and handling
    Corrects the mapping between physical touch pads and their interrupt handlers, updates ISR callback names for clarity, and fixes logic in touch event handling to match the actual hardware mapping. Also improves wakePad management across sleep cycles to prevent stale flags, and lowers the touch threshold for increased sensitivity.
    [FED4.h, FED4_Begin.cpp, FED4_Feed.cpp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]
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2026-01-18 Add touch pad mapping test and improve calibration
    Added a new example sketch for touch pad mapping to assist with hardware/software mapping and troubleshooting. Improved touch sensor calibration in FED4_Touch.cpp by clearing pending flags and disabling interrupts during calibration to prevent false triggers. Minor log message update in FED4_Begin.cpp for consistency.
    [FED4_Begin.cpp, FED4_Touch.cpp]
2026-01-18 Improve touch sensor calibration and audio feedback
    Added stability check to touch sensor calibration at startup and updated the method signature to accept a stability check flag. Refined the reset jingle timing and tone durations for better audio feedback. Adjusted display initialization message positioning and added a button override to exit pellet dispensing. Improved interrupt handling and stability checks in touch calibration for more reliable operation.
    [FED4.h, FED4_Audio.cpp, FED4_Begin.cpp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]
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2026-01-20 Add pokeDuration metric to logging and serial output
    Introduces a new pokeDuration field to the FED4 class, logs it in SD card CSV output, and includes it in serial status reports. Also removes debug print statements from the touch interpretation logic and reduces speaker reset delay for improved performance.
    [FED4.h, FED4_Audio.cpp, FED4_SD.cpp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]
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2026-01-22 Refactor RTC update logic and touch calibration timing
    Added a forceRTCUpdate flag to allow manual RTC updates and reset it after use. Changed touch sensor calibration interval from every 20 to every 200 wake-ups. Simplified touch pad ISR callbacks by removing calibration timing inhibition and reduced touch subsystem stabilization delay.
    [FED4.h, FED4_Audio.cpp, FED4_RTC.cpp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]
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2026-01-28 Improve SD init, LED motion, and sleep sync
    Prepare SPI/display CS before SD initialization and add robust retry/verification logic to improve SD card reliability. Update randomMotion API and behavior: switch from frame count to duration (durationMs), adjust defaults, increase active dots, use probabilistic per-step movement, always maintain a minimum number of dots, and spawn dots across the visible range. Add syncHublink() before entering light sleep in jammed() to ensure state sync. Clean up SD/CS handling and remove redundant SPI endTransaction calls to stabilize SPI usage across display and SD operations.
    [FED4.h, FED4_Begin.cpp, FED4_LEDs.cpp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]
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2026-04-27 Add Mario SFX, SD retry and LED/audio fixes
    Add several Super Mario–style synthesized sound effects (coin, jump, pipe, fireball, mushroom) with implementations and API in FED4.h, and update audio code to use a single sample-rate constant and consistent noise generation. Improve SD initialization robustness by adding a multi-speed retry loop, SPI resets between attempts, cold-boot stabilization delays, and a brief startup retry window in begin() to recover flaky cards. Update LED initialization to enable the front LDO and use explicit WS2812B/GRB configuration; add two front-LED test examples and a minimal bypass example. Replace some test/beep calls with the new Mario sounds (buttons/feedi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
    [FED4.h, FED4_Audio.cpp, FED4_Begin.cpp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]
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2026-07-10 Fix v1.7 hardware examples for PSV polarity and shared pin definitions.
    Correct TPS22917 active-low PSV2/PSV3 enables in the library and sketches, centralize pin usage via FED4_Pins.h, improve battery/ToF troubleshooting examples, and add the v1.7 hardware test log.
    [FED4-Accel-Adafruit.ino, FED4-Battery-Fuel-Guage.ino, FED4-Color-Chase-TouchPads-PhotoGate.ino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]
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2026-07-10 Fix 28BYJ-48 stepper pin order and update v1.7 test log.
    Use IN1/IN3/IN2/IN4 coil sequence in the motor example and library, set 2048 steps/rev, and record hardware validation progress including motor, haptic, temp, and deferred/skipped sketches.
    [FED4-Motor.ino, FED4.cpp]
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2026-07-10 Improve demo audio reliability and add boot startup clip.
    Prioritize I2S feeding during playback, prime the amp with silence, and tune the PIR chirp so melody and motion tones play without crackle or static.
    [FED4-Demo-Hardware.ino]
2026-07-13 Add SleepModes and Solenoids examples with measured power profile.
    Replace DeepSleep with a battery-oriented sleep test, document v1.7 rails and VBATT measurements, and add solenoid alternation hardware validation.
    [FED4-SleepModes.ino]
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2026-07-13 Document GP1A57HR photogate and corrected amp draw in power profile.
    Light-sleep budget now reconciles measured VBATT with ESP32 ~1.1 mA, TCA4307 (stock), and ~2.5–3 mA per GP1A57HR on 3.3V2 (1 kΩ LED); MAX98357A shutdown via EXP_AMP_SD LOW is ~0.6 µA in SleepModes.
    [FED4-SleepModes.ino]
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2026-08-11 Modularize submodule I2C stack and fix RTC-driven capture filenames.
    Extract shared Submodule* helpers for master/slave transport and commands, initialize FED4 DS3231 via PSV2, and build datetime JPEG names from live system clock at capture.
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2026-08-12 Promote NG touch into the library and restructure examples for unit-test alignment.
    Move programs/Hublink/troubleshooting into Archive and UnitTests/Submodules layouts; replace Arduino touchRead with ESP32-S3 touch_sens helpers in src, and point unit tests at FED4_TouchHelpers.
    [ActivityMonitor.ino, BasicFED4.ino, FED4-Accel-Adafruit.ino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]
2026-08-12 Make Demo-Hardware sensor init survive I2C probe failures.
    Use Wire.setTimeOut and bus recovery so a missing or wedged device cannot stall boot past the first WARN.
    [FED4-Demo-Hardware.ino]
2026-08-12 Restore BasicFED4 with event-driven sleep and fix INT_OR/touch wake.
    Align light sleep with unit-test VCOM keepalive (wall-clock budget, GPIO wake off during wait), configure LIS2DH12 INT1 active-low so INT_OR can idle high, and unarchive BasicFED4 on waitUntil/serviceHousekeeping.
    [BasicFED4.ino, FED4.cpp, FED4.h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]
2026-08-13 Fix IDE DateTime resolution with forward declaration and library clangd paths.
    [FED4.h]
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2026-08-13 Integrate LEDC VCOM keepalive and simplify the waitUntil/update API.
    Replace 500 ms CPU VCOM chunks with KEEP_ALIVE LEDC PWM, keep STATUS_LED digital to avoid LEDC clock conflicts, and thin BasicFED4 around FedPad + update().
    [BasicFED4.ino, FED4.cpp, FED4.h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]
2026-08-13 Unarchive FreeFeeding on the feed/update program API.
    Move the replace-when-taken sketch into 1_Programs and drop the legacy run() loop.
    [FreeFeeding.ino]
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2026-08-13 Refine feed retrieval, touch capture, and MIP VCOM for v1.7 programs.
    Add photogate-woken late retrieval and Feed-Pipeline docs, prune dead Pix/friend APIs, capturePoke + waitUntil poke logs, cache ENV on every CSV row, raise VCOM to 30 Hz, and modernize FreeFeeding replace-when-taken.
    [BasicFED4.ino, FED4.h, FED4_Display.cpp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]
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2026-08-13 Add gated Sense master APIs and polish pellet UI / SD error screen.
    Library sense* support is off by default (FED4_ENABLE_SUBMODULE); clear pellet indicators from live well state; refresh SD-error layout for Kyocera MIP.
    [BasicFED4.ino, FED4.h, FED4_Display.cpp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]
2026-08-13 Keep PSV2 on in light sleep to avoid SD/SPI MIP corruption.
    Shared SCK/MOSI with an unpowered SD card caused display artifacts; sleep now leaves 3.3V2 on with LEDC VCOM KEEP_ALIVE, Demo-aligned refresh, and SPI reclaim after logData.
    [BasicFED4.ino, FED4.h, FED4_Display.cpp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]
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2026-08-14 Replace I2C Sense submodule with TRRS TRIG+UART; drop it from BasicFED4.
    Sense moves to TRIG/DATA on TRRS2/3 with async capture; BasicFED4 stays left-poke feed only while submodule work is on hold.
    [BasicFED4.ino, FED4-I2C-Scanner.ino, FED4.h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]
2026-08-14 Document v1.7 hardware features in the README.
    Replace the mixed capabilities list with a board-focused feature inventory and link CHIPSETS.md.
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2026-08-25 Fix touch wake on high-baseline pads with noise-based characterization.
    Sample mean/std at init, set per-pad absolute wake thresholds, and rescue re-characterize if sleep release-wait sticks so Left is as wakeable as Center/Right.
    [FED4.h, FED4_Begin.cpp, FED4_Sleep.cpp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]
2026-08-25 Improve poke wake identity, pin map, and post-poke UI latency.
    Trust NG active latch / smooth−benchmark for light-sleep pad ID, correct L/C/R GPIOs, and use FedUpdateMode::Poke to skip sensors and full redraw after touch.
    [FED4.cpp, FED4.h, FED4_Display.cpp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]
2026-08-26 Add touch NVS cal WIP, ToF strip unit test, and Demo I2C healthy fix.
    Mark FED4-Touch-Calibrate as in progress; restore Wire after i2cBusHealthy
    in Demo-Hardware so the first sensor probe (BME680) no longer fails.
    [FED4-Demo-Hardware.ino, FED4.h, FED4_Touch.cpp]
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2026-08-26 Fix face-on touch GPIO map and harden post-sleep poke ID.
    Verify Left/Center/Right as GPIO1/3/2, and identify pokes via wake latch
    plus absolute (smooth−idle) confirm so rise% first-cross no longer steals Center/Left.
    [FED4_Pins.h, FED4_Touch.cpp]
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2026-09-10 Add touch-drift plots from the 5 Sep 2026 _T.CSV log.
    PNG charts of Smooth/Idle/Bench, temperature, residuals, and pokes, plus a local HTML gallery so the figures can be opened without the Cursor canvas viewer.
2026-09-15 long poke duration bug
    The bug:
    At 2 s, rescue used to run fed4TouchCharacterizePads() whenever software looked stuck — even with a finger on the well.
    Char samples Smooth for ~1.7 s and writes the mean into Idle. Sampling a loaded pad raises Idle toward the poke (15 Sep log: IdleR 9943 → 17809 after a 500 ms hold). Later pokes vs that Idle look weaker or never fire. So a Rechar row sitting right after a ~500 ms Poke row means: we recalibrated while loaded. That is the failure, not “rescue worked.”
    What 1.7.1 considers success
    Rescue is only for empty pads, stale software Idle:
    Do not rechar if wakePad != 0 (we just identified a poke)
    Do not rechar if HW still active (smooth − b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
    [FED4.h, FED4_Begin.cpp, FED4_Sleep.cpp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]
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
